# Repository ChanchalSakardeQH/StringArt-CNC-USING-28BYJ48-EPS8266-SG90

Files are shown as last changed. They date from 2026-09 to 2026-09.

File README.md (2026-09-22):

# ESP8266 String Art CNC

An ESP8266 string art machine you drive from your phone. A 28BYJ-48 stepper
turns a disc of nails, an SG90 servo hooks the thread onto each one, and a
0.96" OLED shows where it is in the sequence.

Everything runs on the board itself. The web page it serves turns a photo into
a nail sequence, designs a printable base template for the nail ring, sends the
sequence to the machine and drives it — with no app, no desktop software and no
internet connection.

---

## Contents

- [Features](#features)
- [Repository layout](#repository-layout)
- [Hardware](#hardware)
- [Wiring](#wiring)
- [Flashing](#flashing)
- [First run](#first-run)
- [Setting up a new machine](#setting-up-a-new-machine)
- [Making a piece](#making-a-piece)
- [How the wrap works](#how-the-wrap-works)
- [The OLED display](#the-oled-display)
- [Electronics enclosure](#electronics-enclosure)
- [Power cuts](#power-cuts)
- [When the wrong nail turns up](#when-the-wrong-nail-turns-up)
- [Checkpoint test run](#checkpoint-test-run)
- [Which gear ratio](#which-gear-ratio)
- [Configuration in the sketch](#configuration-in-the-sketch)
- [HTTP API](#http-api)
- [Files on flash](#files-on-flash)
- [Troubleshooting](#troubleshooting)
- [Tests](#tests)
- [Known limitations](#known-limitations)
- [Licence](#licence)
- [Credits](#credits)

---

## Features

- **Photo to string art in the browser** — upload, crop, choose nail and chord
  counts, and watch the solver build the image. Download the steps as text or
  the result as SVG.
- **Greeting card PDF** — the photo and finished art on one A4 landscape sheet,
  folded down the middle, with an optional title and message.
- **Base template designer** — a printable, numbered nail ring sized to your
  disc, with SVG export and an optional laser-cut outline.
- **Automatic thread wrapping** — the disc and servo together trace a loop
  around each nail, following the direction of travel so it works whichever
  way the chord runs.
- **Everything tuned by eye** — servo angles and the disc's wrap positions are
  sliders the hardware follows live as you drag.
- **Calibration** — re-sync the nail at the feeder, measure the real
  steps-per-turn, and re-home periodically on long runs.
- **Checkpoint test run that learns** — optionally stops every N nails to ask
  whether the right nail is at the feeder, fixes the run from your answer, and
  works out the real steps-per-turn from a series of them.
- **Resume after a power cut**, with detection of a move that was interrupted.
- **Live time estimate** from measured cycle times, not guesses.
- **OLED dashboard** showing the current and next nail, progress, time left,
  and the IP address at boot.
- **Printable electronics enclosure** — a 6.3 × 3.3 × 5 in box with the OLED
  set into its front, a lid, and a universal component tray. Plus a desk stand
  for the display.
- **No extra libraries** — builds on the bare ESP8266 core.
- **Free software** — GPL v3 or later, with every outside author credited.

---

## Repository layout

```
esp8266_string_art_standalone.ino   firmware
web_page.h                          the web UI, one PROGMEM string
oled_display.h                      OLED driver and dashboard

parts.py                            machine parts -> stl/
fitcheck.py                         checks every machine-part bolt fits
assembly.py                         renders the assembled machine
enclosure.py                        electronics box, lid, tray, OLED mount -> stl/
enclosure_fitcheck.py               checks every enclosure part fits
enclosure_render.py                 renders enclosure_guide.png
stl/                                all the printed parts
PRINTING.md                         printing and assembly guide

tests/                              firmware compile, regression + end-to-end tests
  run.sh  auto_start.cpp  checkpoint_e2e.cpp  page_auto.js  stub/

oled_wiring.png  oled_screens.png  assembly_guide.png  enclosure_guide.png
README.md  CHANGELOG.md  LICENSE  THIRD_PARTY_NOTICES.md
```

The Arduino IDE needs the `.ino` to sit in a folder with the same name. Clone
the repo into a folder called `esp8266_string_art_standalone`, or copy the
three firmware files into one.

**The three firmware files must stay together.** `web_page.h` is separate
because the Arduino preprocessor corrupts very large raw string literals in
`.ino` files but leaves `.h` files alone. `oled_display.h` is separate so its
drawing code can be compiled and tested on a PC.

---

## Hardware

| Part | Notes |
|---|---|
| ESP8266 board | NodeMCU 1.0 or similar |
| 28BYJ-48 stepper + ULN2003 board | 5 V version |
| SG90 micro servo | The thread hook |
| External 5 V supply | 2 A. Powers the motor and servo — never run them from the ESP8266's regulator |
| 0.96" OLED, SSD1306, I2C | *Optional.* 128×64. Four-pin I2C modules only, not SPI |
| Microswitch + 10 kΩ resistor | *Optional.* Home position sensor |
| Nail disc | Plywood or MDF, nails around the rim |
| Thin tube | Brass or steel, about 2 mm, for the thread to run through |

For the thread to stay on a nail, three things must be true, and none of them
can be fixed in firmware: the nails need heads (panel pins or brads, not
headless pins), the tube must carry the thread past the outside of the nail
ring at shank height, and the spool needs light tension.

---

## Wiring

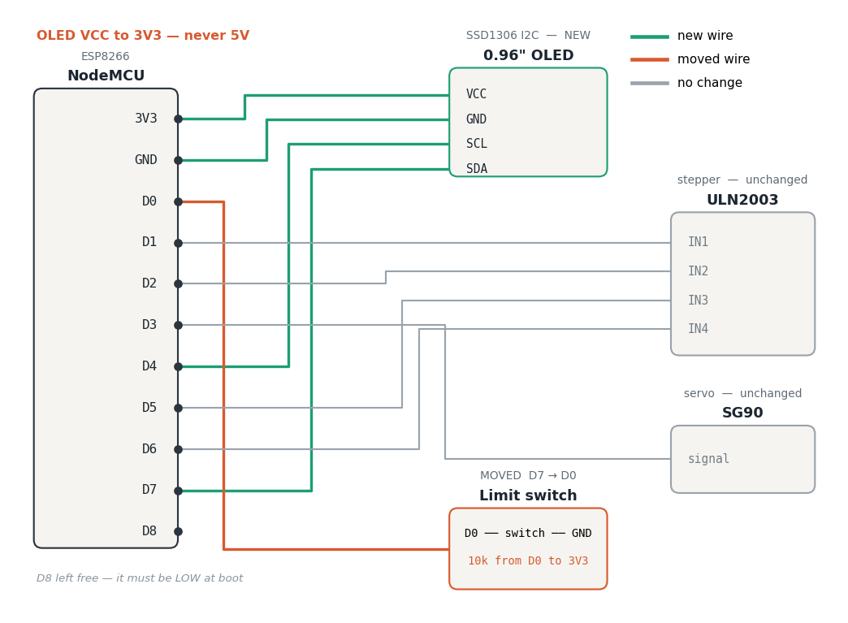
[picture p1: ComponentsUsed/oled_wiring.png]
Wiring diagram


```
ULN2003 IN1  ->  D1  (GPIO5)
ULN2003 IN2  ->  D2  (GPIO4)
ULN2003 IN3  ->  D5  (GPIO14)
ULN2003 IN4  ->  D6  (GPIO12)
ULN2003 +    ->  external 5 V
ULN2003 GND  ->  common ground

SG90 signal  ->  D3  (GPIO0)
SG90 V+      ->  external 5 V
SG90 GND     ->  common ground

OLED VCC     ->  3V3            3.3 V -- never 5 V
OLED GND     ->  GND
OLED SDA     ->  D7  (GPIO13)
OLED SCL     ->  D4  (GPIO2)

Limit switch ->  D0  (GPIO16) and GND
10k resistor ->  from D0 to 3V3
```

**Share ground, not power.** The motor and servo draw current spikes the
ESP8266's regulator can't supply while WiFi is transmitting. Feed them from the
external 5 V supply and tie every ground together.

**Power the OLED from 3V3.** Its I2C pull-up resistors connect to whatever
powers it, and the ESP8266's pins are not 5 V tolerant.

**SCK and SCL are the same pin.** Many 4-pin OLED modules label the clock
**SCK** instead of SCL; wire it to D4 all the same. Check the pin count first,
though: a module with 6 or 7 pins (RES, DC, CS and so on) is the SPI version,
and SCK means something different there. The firmware only supports I2C.

**Upgrading from before 1.12.0?** The limit switch used to be on D7. It has
moved to D0 to make room for the display, and now needs the 10 kΩ resistor.
See the [changelog](CHANGELOG.md) for the full list.

### Why the pins are where they are

The ESP8266 has few free pins, and several have jobs at boot.

- **D1 and D2** are the usual I2C pair, but they drive the stepper.
- **D8** must be LOW at boot. An I2C pull-up would hold it HIGH and the board
  would not start.
- **D0** cannot do I2C — it sits on a separate register the driver can't use.
- That leaves **D4 and D7** for the display, which pushes the limit switch to
  **D0**.
- **D0 has no internal pull-up**, so the switch needs the 10 kΩ resistor to
  3V3. Without it the pin floats and homing reads noise.
- **D3 and D4** must read HIGH at reset. The servo input and the OLED's
  pull-up both leave them HIGH, so the board boots normally.
- **D4** also drives the onboard blue LED on most boards. It flickers faintly
  while the display updates. That is harmless.

---

## Flashing

1. In the Arduino IDE Board Manager, install **esp8266** by ESP8266 Community.
2. **Tools → Board** → *NodeMCU 1.0 (ESP-12E Module)*, or your board.
3. **Tools → Flash Size** → any option with a LittleFS partition.
4. Open the `esp8266_string_art_standalone` folder containing the three firmware files.
5. Set `WIFI_SSID` and `WIFI_PASSWORD` near the top of the `.ino`.
6. If you fitted the limit switch and resistor, set `HAS_LIMIT_SWITCH = true`.
7. Upload.

No libraries to install. WiFi, the web server, mDNS, LittleFS, Servo and Wire
all come with the ESP8266 core, and the OLED driver is in `oled_display.h`.

---

## First run

Power it up and watch the OLED. It shows **Joining WiFi**, then the IP address
to open and `stringart.local`, for eight seconds.

If it can't join your network it starts its own: an open network called
**StringArtCNC**. Connect to it and open **192.168.4.1**. The OLED shows this
too.

Without a display, the address is printed on the serial monitor at 115200 baud.
With no sequence loaded, the OLED keeps showing the address until you load one.

---

## Setting up a new machine

Do these once, in this order. Each step depends on the one before it.

**1. Set the nail count.** Section 1 · Design → **Nails**. This one value is
shared by the design, the base template and the machine, so it only needs
setting once. Settle on it before tuning anything else — changing it later
resets the wrap settings, because step counts don't carry over to a different
nail spacing.

**2. Print and fit the base template.** Section 4 · Base template. Print the SVG
at 100% scale with fit-to-page turned off, glue it face up on the disc, and
drill at every red dot. Nail 0 is at three o'clock and numbering runs
clockwise.

**3. Home the disc.** Line nail 0 up with the feeder and press **Set Home**. With
a limit switch fitted, press **Find Home (limit switch)** instead.

**4. Check the direction.** Advanced settings → Motor → **Run direction test**.
The disc visits nails at the quarter points. If the nail arriving at the feeder
isn't the one named on screen, turn on **Reverse rotation direction** and home
again.

**5. Set the servo angles.** Advanced settings → Feeder servo (SG90) angles.
Drag the sliders and the arm follows. **Rest** sits clear of the nails; **Feed**
has the tube out past the ring. **Swing rest → feed → rest** plays the real
motion.

**6. Set the wrap.** Advanced settings → Wrap cycle. Drag **Ahead of the nail**
and **Behind the nail**; the disc follows. The defaults are half a nail each
way. Then use **Walk through one wrap by hand**, one button at a time, with
thread on. If it hooks by hand it will hook on the run. Turn on **Preview as if
the disc arrived travelling −** and walk through again to check the other
direction.

**7. Measure the steps per turn** *(recommended before long pieces)*. Section 2 ·
Wrap → Calibrate the nail position. **Spin** ten turns, then enter how many
nails past the start it finished and press **Correct**.

---

## Making a piece

**Design.** In section 1, choose a photo, crop it to the circle, set the chord
count and line weight, and press **Generate string art**. More chords make a
darker, more detailed result and a much longer wrap. Download the steps or an
SVG if you like.

**Greeting card.** Under the Design section, **Greeting card (A4 PDF)** puts your
photo and the finished art on one A4 landscape sheet: art and title on the
cover, photo and message inside. Print at 100% with fit-to-page off.

**Send.** Press **Send to this machine**.

**Wrap.** In section 2 the large number is the nail at the feeder. **Next →**
advances one nail; **Start Auto** runs the sequence hands-free with a pause
between nails. Under the progress bar you get elapsed time, time left, the
clock time it will finish, and seconds per nail.

**Go to step #** jumps to a point in the sequence and carries on from there.
**Go to nail #** turns the disc without changing your place.

---

## How the wrap works

A feeder that swings out and back along the same line cannot hook a nail. That
path encloses nothing, so the thread touches the nail and lets go. The tube has
to travel around the nail. With one servo, the disc supplies half of that loop:

| Phase | What moves | Default |
|---|---|---|
| Approach | Disc, to just past the nail | — |
| Settle | Nothing — let the disc stop | 800 ms |
| Tube in | Servo swings to the feed angle | 900 ms |
| Wait | Let the thread seat | 400 ms |
| Sweep | Disc, back across the nail | — |
| Wait | Let the thread hook | 400 ms |
| Tube out | Servo swings back to rest | 900 ms |
| Recover | Let the thread settle | 400 ms |
| Land | Disc onto the nail | — |

The loop takes its direction from the way the disc travelled to reach the nail:
it runs past the nail, sweeps back across, and lands. The thread always trails
behind the direction of travel, so this keeps the tube on the far side from it.
A loop with a fixed direction wraps correctly one way round and drops the thread
the other.

The servo is moved a couple of degrees at a time rather than sent straight to
its angle. `Servo.write()` has no speed setting, so an SG90 otherwise slams to
position.

All the timings are in Advanced settings → Timings. If the thread snatches,
raise **Settle before feed** first. Usually the disc hasn't stopped moving yet.

---

## The OLED display

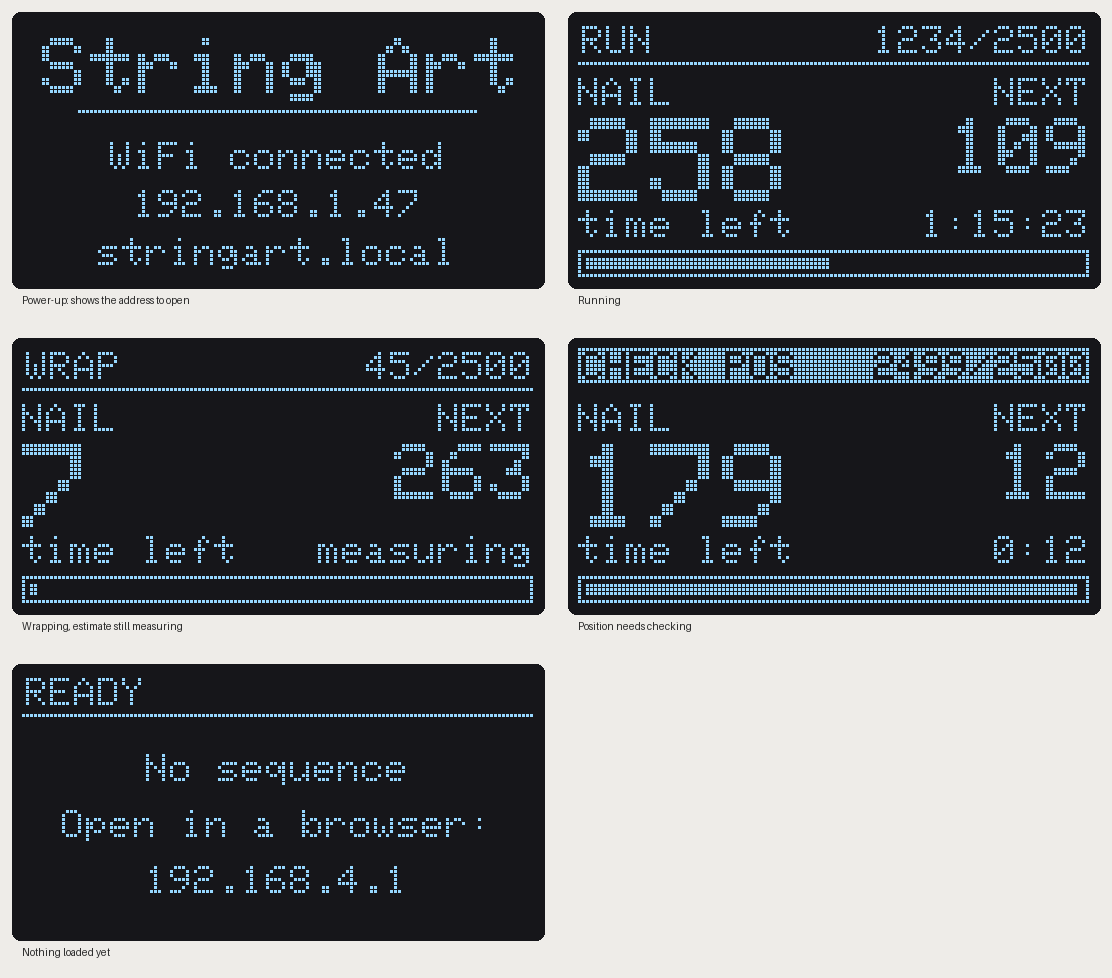
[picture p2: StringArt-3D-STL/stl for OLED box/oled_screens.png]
OLED screens


- **Header:** the machine's state — RUN, WRAP, FEED, HOMING, PAUSED, DONE — and
  the step count. It turns into a highlighted bar for **CHECK POS** (position
  not verified after a power cut) or **HOME FAIL**.
- **Centre:** the nail at the feeder in large digits, and the next nail.
- **Bottom:** a live countdown of time left, and a progress bar.

The display is found automatically at address 0x3C or 0x3D. If none is
connected, the firmware carries on without it. If the text comes out upside
down, turn on **OLED display upside down** in Advanced settings → Motor.

It never slows the machine down. It skips redrawing while the disc is moving,
sends the picture in small pieces between other work, and sends nothing when
the numbers haven't changed.

---

## Electronics enclosure

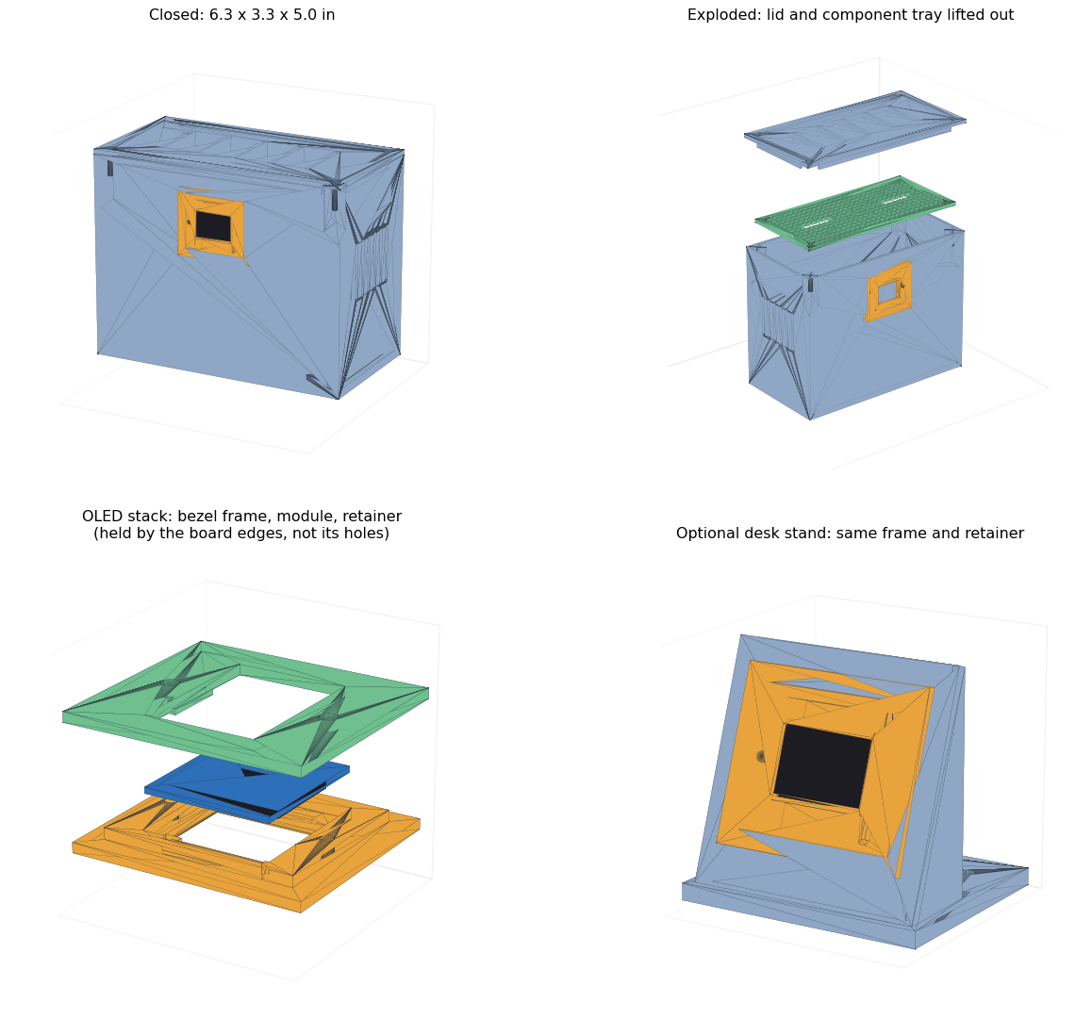
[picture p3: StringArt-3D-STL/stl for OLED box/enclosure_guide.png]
Enclosure


A box for the NodeMCU, the ULN2003 board and the wiring, with the OLED set into
its front. **6.3 × 3.3 × 5 in outside with the lid on** (160 × 84 × 127 mm);
inside it's 155 × 79 × 121 mm. Every size is a named constant at the top of
`enclosure.py`.

| Part | Print it | What it does |
|---|---|---|
| `enclosure_box.stl` | Upright, open top up | The box. OLED opening in front, cable port and DC jack hole in the back, vents in both ends |
| `enclosure_lid.stl` | Outer face down | Screws onto four corner bosses |
| `enclosure_tray.stl` | Flat | Perforated plate on four standoffs. The 0.1 in hole grid takes M2.5 or M3 self-tapping screws or cable ties, so any board fits without knowing its hole pattern |
| `oled_frame.stl` | Front face down | The bezel. Holds the display by its board edges |
| `oled_retainer.stl` | Flat, fingers up | Clamps the frame to the wall and keeps the display in |
| `oled_stand.stl` | On its base | *Optional.* Desk stand for the display. Uses the same frame and retainer |

None of them need support. The box's OLED opening has a 38 mm flat top edge,
which most printers bridge cleanly. The box needs a bed of at least
165 × 90 mm and 130 mm of height.

### How the display is held

The frame goes in from the front, and the retainer goes on from inside. Two
screws through the retainer into the frame clamp the wall between them, and at
the same time the retainer's two fingers keep the display's board seated in its
pocket. So the same two screws do both jobs, and nothing shows on the front.

The display is held **by its board edges, not its mounting holes.** The drawing
it was designed from gives the board, glass and flex-cable sizes, but not the
hole spacing — so nothing depends on it. The fingers leave the board 0.1 mm of
play rather than squeeze the glass.

### One measurement before printing the frame

The drawing doesn't say exactly where the glass sits up the board. Measure the
distance from the **top edge of the board** (the pin header side) to the **top
of the black glass**, and set `GLASS_TOP` in `enclosure.py`. The default, 5.5 mm,
assumes the glass is centred. The glass pocket allows 1 mm either way, so
anything close is fine. The frame is a 4 cm³ print, so a second try costs
about fifteen minutes; the box never needs reprinting for this.

### Screws

| Where | What |
|---|---|
| Lid to box | 4 × M3 × 8 countersunk, self-tapping |
| Tray to standoffs | 4 × M3 × 6 self-tapping |
| OLED retainer to frame | 2 × M3 × 6 self-tapping |
| Box to machine base | 4 × M3, through the floor |
| Boards to tray | M2.5 or M3 self-tapping, or cable ties |

After changing anything in `enclosure.py`, run it, then
`enclosure_fitcheck.py`. The check places every part in its assembled position
with a model of the display, and confirms nothing collides, that the bezel and
retainer really clamp the wall, and that every screw meets its hole.

---

## Power cuts

The disc holds its position when the power goes, so nothing physically moves.
What matters is whether the firmware still knows where the disc is. Progress is
saved twice per nail — when a move starts and when it lands — which covers both
cases:

- **Cut while stopped between nails:** the saved position is exact. It picks up
  on the same step.
- **Cut during a move:** the disc stopped somewhere between two nails. The
  firmware restores where it was heading, marks the position unverified, and the
  OLED and web page show **CHECK POS**. Home before carrying on. Your progress is
  kept either way.

With a limit switch, **Find home on power-up** (Advanced settings → Motor) homes
automatically at boot and drives back to the saved nail. It does not restart the
run on its own, since the thread may be loose.

---

## When the wrong nail turns up

On a long run the nail at the feeder can stop matching the one on screen. There
are three different causes, and they need different fixes.

**Out by the same amount every time.** Section 2 · Wrap → Calibrate the nail
position. Jog the disc until the right nail lines up, then enter which nail it is
and press **Set**. Your place in the sequence is untouched.

**A little further out with every turn.** The steps-per-turn figure is wrong.
**Spin** ten turns, enter how far past the start it finished, and press
**Correct**. Ten turns can measure an error of 0.05%.

**Wandering at random, even after both fixes.** The motor is losing steps. The
28BYJ-48 can't sense this, so the fixes are mechanical: raise the step delay,
make the disc lighter, and check nothing is rubbing. **Re-home every N nails**
(needs the limit switch) keeps a long run on track, but it works around the
problem rather than fixing it.

---

## Which gear ratio

The 28BYJ-48 is sold as a 64:1 gearbox, which gives **4096** half-steps per
turn of the output shaft. That's what the firmware starts with. Many units are
actually **63.68395:1** — the ratio you get by multiplying out the real gear
teeth — which gives **4075.77**. The difference is about half a percent, or
roughly 1.8° by the time the disc has gone once round.

You don't have to know which one you have. Section 2 · Wrap → Calibrate the
nail position → **Spin** ten turns, enter how many nails past the start it
finished, and press **Correct**. The firmware works out the real figure and
saves it. A disc that finishes 18 nails short over ten turns measures 4075.6 —
the tooth-count ratio, found by measurement.

Within a single turn the choice barely matters: rounding to the nearest
half-step is at most ±0.044°. It only shows up as error that builds over whole
turns.

---

## Checkpoint test run

A calibration run you do with thread on, on a real sequence. **It's off by
default.** Turn it on in Section 2 · Wrap → Calibrate the nail position →
**Pause to check the nail during a run**, pick how often, and start the run.

Every Nth nail, the disc stops **on** the nail, before wrapping, and asks:

> Checkpoint: is nail **258** centred in front of the feeder?

- **If it is**, press **Yes, it's centred**.
- **If it's slightly off**, use the nudge buttons (±1 step, ±1 nail) until it's
  centred, then press **Yes**. The nudge is measured to the step, and that
  precision is what lets it learn.
- **If it's well off**, type the nail that's actually there and press **Use**.
- **Skip this checkpoint** carries on without learning from it.

The OLED shows **CONFIRM?** and the browser tab gets a ● marker while it's
waiting, so a question isn't missed during a long run.

### What your answers do

**They fix the run straight away.** Each answer re-syncs the numbering, then
the machine wraps that nail and carries on.

**They teach it.** The firmware plots the total correction so far against how
far the disc has turned, and fits a straight line through the answers:

- a **constant error** — the same every time — is a position offset;
- an error that **grows as the disc turns** means the steps-per-turn figure is
  slightly wrong, and the slope says by how much;
- answers that **don't fall on a line** mean missed steps. Those are random and
  can't be learned; the panel says so and points you at the mechanics instead.

It only believes a slope once it has **5 checkpoints spread over 2 turns** and
at least two nails' worth of drift. Until then it only corrects the offset.
With **Correct steps per turn automatically** on (the default), it applies the
new figure at the next checkpoint and tells you what changed. Turn that off to
review the suggestion and apply it with **Use suggested steps per turn**.
**Forget what it learned** puts steps-per-turn back to what it was.

### How long a test run takes

With a question every 25 nails, it learned the steps-per-turn at the **6th
checkpoint**, about 150 nails in, for motors both slower and faster than the
firmware assumed. **Plan on 8–10 checkpoints.** Turning checkpoints off before
it has learned leaves the motor uncalibrated — the run carries on, but the drift
it was about to correct stays.

### Does it work?

It was tested by running the real firmware — `setup()`, `loop()` and the web
handlers — on a PC, against a simulated disc whose true steps-per-turn differed
from what the firmware assumed, answering every question as a person would.
Each run is 600 nails with a checkpoint every 25:

| Motor | Answers | Steps/turn learned | Wrong nails, last 200 |
|---|---|---|---|
| 4075.77 steps/turn | nudged to centre | 4075.65 | 0 |
| 4110.00 steps/turn | nudged to centre | 4109.94 | 0 |
| 4096.00 (already right) | nudged to centre | unchanged | 0 |
| 4075.77 steps/turn | whole nails only | within 0.9 steps | up to 30% |

So **centring before you answer matters a lot**. A whole-nail answer can leave
the disc up to half a nail off, and a tiny drift then tips it onto the
neighbouring nail. With a motor that's already right, it never changes
anything. `sh tests/run.sh` repeats these runs — see [Tests](#tests).

After a test run has settled the steps-per-turn, turn checkpoints off for
normal runs.

---

## Configuration in the sketch

Most settings live in the web page and are saved to flash. These few are set in
the `.ino` before uploading:

| Constant | Default | Purpose |
|---|---|---|
| `WIFI_SSID`, `WIFI_PASSWORD` | placeholders | Your network |
| `AP_FALLBACK_SSID` | `StringArtCNC` | Network it starts if yours fails |
| `HOSTNAME` | `stringart` | Reached at `stringart.local` |
| `HAS_LIMIT_SWITCH` | `false` | Set `true` once the switch and resistor are fitted |
| `MOTOR_GEAR_RATIO_X100000` | `6400000` | 64:1. A starting point only — see [Which gear ratio](#which-gear-ratio) |
| `DEF_*` | see file | Values used on first boot and by **Restore defaults** |

**Restore defaults** in Advanced settings puts every web setting back to the
`DEF_*` values without re-flashing.

---

## HTTP API

The page talks to the machine over four endpoints, all CORS-enabled.

| Method | Path | Purpose |
|---|---|---|
| `GET` | `/` | The web page |
| `GET` | `/status` | JSON: position, progress, timings, every setting, detected hardware |
| `POST` | `/upload` | The sequence, one nail number per line |
| `POST` | `/config` | Form fields for any setting; `reset=1` restores defaults; `recalcWrap=1` recomputes the wrap for the nail count |
| `POST` | `/action` | `cmd=` plus `value=` where needed |

**Actions:**

| `cmd` | `value` | Does |
|---|---|---|
| `next`, `prev` | — | Move one step through the sequence |
| `start`, `stop` | — | Auto-run on or off |
| `gotostep` | step | Jump to a step, taking progress with it |
| `goto` | nail | Turn the disc to a nail, progress unchanged |
| `home` | — | The nail at the feeder becomes nail 0 |
| `findhome` | — | Seek the limit switch. Refused if none is fitted |
| `feed` | — | One servo cycle, rest → feed → rest |
| `wraptest` | — | One full wrap on the current nail |
| `wrappreview` | steps | Park the disc this many steps from the current nail |
| `servotest` | angle | Move the servo to an angle |
| `jog` | steps | Nudge the disc without changing the numbering |
| `setnail` | nail | "The nail at the feeder is this one" — re-syncs |
| `calmove` | turns | Spin whole turns for steps-per-turn calibration |
| `calreport` | nails | Report how far past the start it finished |
| `verify` | nail, `-1` or `-2` | Answer a checkpoint: the nail really at the feeder, `-1` "yes, centred", `-2` skip |
| `learnapply` | — | Use the steps-per-turn the checkpoints suggest |
| `learnforget` | — | Clear what the checkpoints learned and restore the previous steps-per-turn |

```bash
curl http://stringart.local/status
curl -X POST http://stringart.local/action -d "cmd=goto&value=258"
curl -X POST http://stringart.local/config -d "feederSettleMs=1000"
```

---

## Files on flash

| Path | Contents |
|---|---|
| `/sequence.csv` | The nail sequence, one number per line |
| `/state.txt` | Step, disc position, target, whether a move was in progress, elapsed time, average time per nail |
| `/config.txt` | Every setting, one value per line |

Settings files from older firmware load fine. Any value that's missing falls
back to its default rather than zero.

---

## Troubleshooting

**The wrong nail arrives, and it's always the mirror image** — you ask for 258
and get 102. The rotation direction is reversed. Turn on **Reverse rotation
direction** in Advanced settings → Motor, then home again.

**The thread hooks on some nails but not others.** Check both approach
directions with **Test wrap, coming from −** and **Test wrap, coming from +**.
Both should make the same small reversing move at the nail. If both do but the
thread still drops, go through the three mechanical checks under
[Hardware](#hardware): nail heads, the tube crossing the ring, and spool tension.

**Start Auto does nothing.** Look at the line under the button: it says why
auto isn't moving — the sequence is finished, it's waiting for a checkpoint
answer, a calibration spin is running, or it's homing. If nothing shows and the
button still says Start Auto after you press it, the page isn't reaching the
board: check the IP on the OLED and reload. After flashing new firmware, reload
the page too, so the browser isn't running the old copy.

**The motor hums but doesn't turn.** The step delay is too short for the load,
or a coil wire is loose. Raise the step delay to 3–5 ms first. If it still
won't move, check that the four LEDs on the ULN2003 light in sequence.

**Find Home never completes.** Check that `HAS_LIMIT_SWITCH` is `true`, that
the switch connects **D0** to GND when pressed, and that the 10 kΩ resistor
runs from D0 to 3V3. Without the resistor D0 floats and never reads cleanly. The
status line shows the switch's live state, so press it by hand and watch it
change. The search gives up after a turn and a quarter and reports **HOME FAIL**.

**Find Home does nothing at all.** `HAS_LIMIT_SWITCH` is `false`, so homing is
refused. Use **Set Home** instead: line nail 0 up with the feeder by hand and
press it.

**The OLED stays blank.** Check that it's powered from 3V3, that SDA goes to D7
and SCL to D4 (swapping them is the most common mistake), and that it's an I2C
module — four pins marked VCC, GND, SCL, SDA. The web page shows **Display
found at 0x3C**, or says none was detected.

**The board won't boot after wiring the OLED.** Something is holding D3 or D4
LOW at power-up. Check the OLED isn't wired to D8, and that nothing else is
connected to D4.

**The thread snatches or feeds unevenly.** Raise **Settle before feed** in
Advanced settings → Timings. The disc usually needs longer to stop than it looks.

**The page loads but the buttons do nothing.** Check the IP on the OLED. A
bookmarked address stops working when your router hands out a new one.

**It's on 192.168.4.1 instead of your network.** It couldn't join your WiFi and
started its own. Check the network name and password — and note the ESP8266
only works with 2.4 GHz networks, not 5 GHz.

---

## Tests

```bash
sh tests/run.sh
```

Needs only `g++`. It runs four stages:

1. **Compiles the whole firmware** on a PC, against stand-in versions of the
   ESP8266 core's headers in `tests/stub/`, with all compiler warnings on. This
   catches typos, missing declarations and type errors anywhere in the sketch
   without the Arduino IDE or a board.
2. **Start/Stop Auto regressions**: the real firmware, checked for the first
   move starting straight away, auto-run surviving a calibration spin, and
   Start refusing a finished sequence with a reason.
3. **The checkpoint feature end to end**: the real `setup()`, `loop()` and
   web handlers, on a simulated disc, for three motors.
4. **The web page**: checks the firmware's real `/status` reply is valid JSON,
   then — if `jsdom` is installed — loads the real page and clicks Start and
   Stop Auto. To enable that part: `cd tests && npm install jsdom`.

The stand-ins only need to be close enough to compile and drive the firmware;
they aren't a full emulator. A clean run here doesn't replace flashing the
board, but it catches most mistakes long before that.

The printed parts have their own checks: `fitcheck.py` and
`enclosure_fitcheck.py`.

---

## Known limitations

- **The stepper can't sense missed steps.** The 28BYJ-48 has no feedback, so a
  missed step goes unnoticed until the wrong nail arrives. The limit switch and
  periodic re-homing work around this; they don't prevent it.
- **The 28BYJ-48 is weak.** It has little torque above about 15 rpm. A heavy
  disc or a short step delay will make it lose steps.
- **Wrapping depends on the mechanics.** The firmware controls the timing and
  the path, but whether the thread stays on depends on nail shape, tube position
  and thread tension. Expect to tune these on your own machine.
- **Only one servo axis.** The disc has to make half of each wrap loop, so every
  nail costs two short extra moves.

---

## Licence

ESP8266 String Art CNC is free software: you can redistribute it and/or modify
it under the terms of the **GNU General Public License, version 3 or (at your
option) any later version** — see [LICENSE](LICENSE). It comes with no
warranty.

In short: anyone can use, study, change and share it, including commercially,
but anything distributed that's built from it must also be under the GPL, with
its source available. The web page shows this notice at the bottom of the
sidebar, as the GPL asks interactive programs to.

Each source file starts with an `SPDX-License-Identifier` line. Two files also
contain other people's work under their own licences:

| File | Licence |
|---|---|
| `web_page.h` | GPL-3.0-or-later AND MIT (bundles Cropper.js) |
| `oled_display.h` | GPL-3.0-or-later AND BSD-2-Clause (the 5×7 font) |

---

## Credits

This project builds on other people's work. Their credits and licences are kept
as they were, in the files themselves and in full in
[THIRD_PARTY_NOTICES.md](THIRD_PARTY_NOTICES.md).

- **Cropper.js** 1.6.1 by **Chen Fengyuan** — MIT. Bundled into the web page,
  unmodified, with its copyright banner.
- **5×7 font** ("glcdfont") by **Adafruit Industries**, from Adafruit-GFX-Library
  — BSD 2-Clause. The OLED driver around it was written for this project.
- **Base template designer** and coding of  *StringArt-Design* by
  **Chanchal Sakarde**.

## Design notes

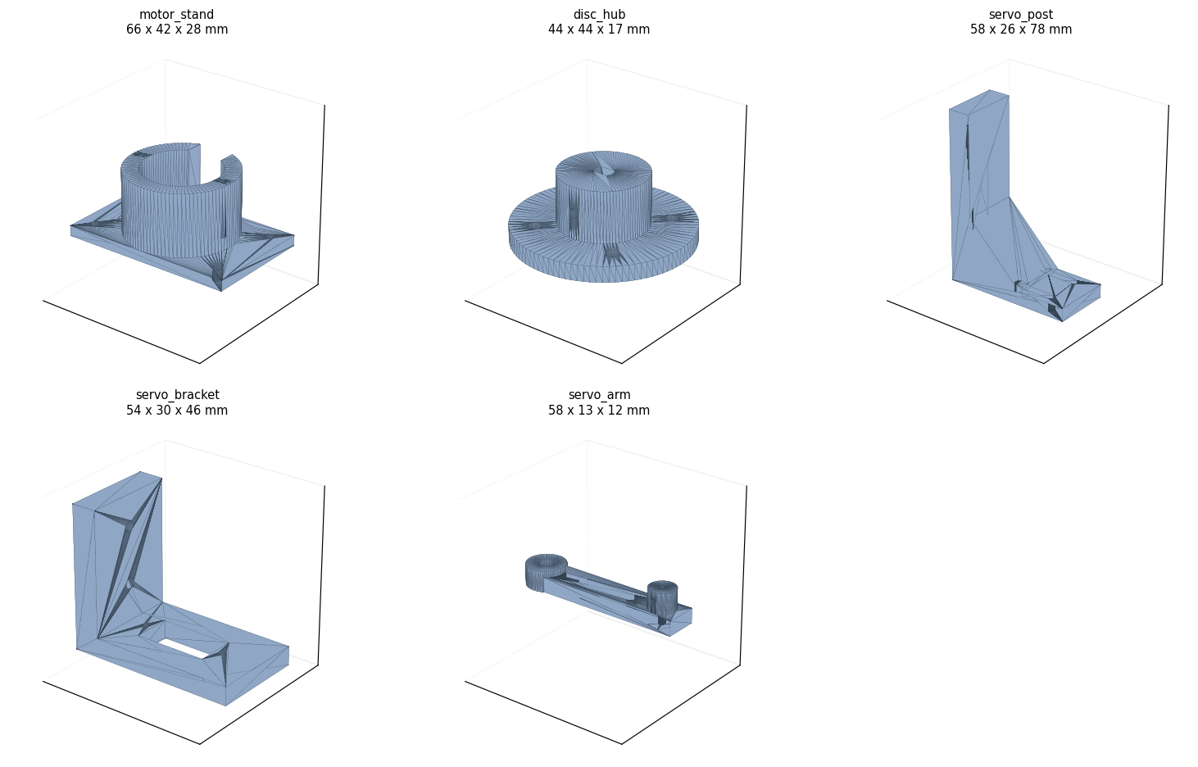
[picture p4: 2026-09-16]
StringArt-3D-STL/preview.png

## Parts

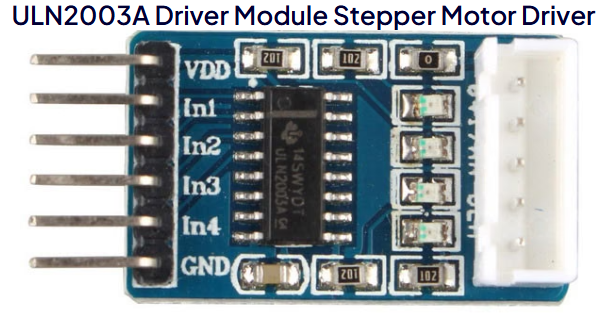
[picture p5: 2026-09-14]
ComponentsUsed/ULN2003A-DriverModule.png

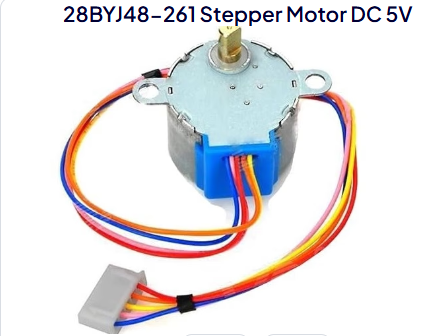
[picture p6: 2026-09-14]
ComponentsUsed/28BYJ48-261StepperMotorDC5V.png

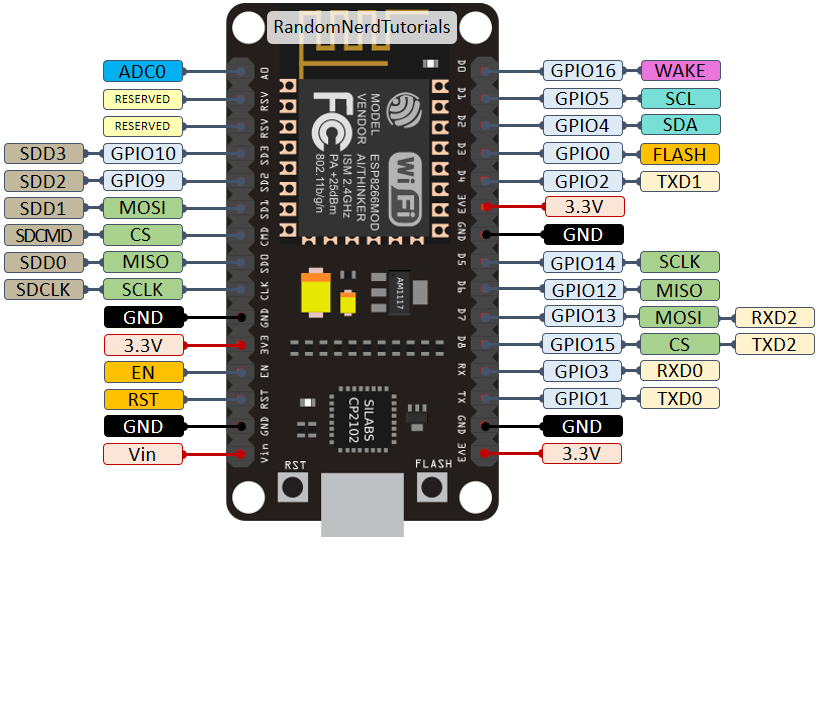
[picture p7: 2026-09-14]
ComponentsUsed/ESP8266-pin.png

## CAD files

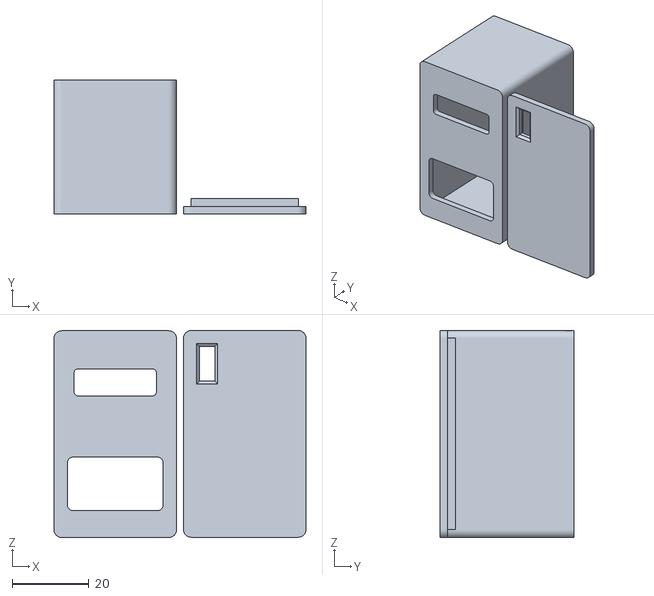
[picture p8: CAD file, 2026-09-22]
StringArt-3D-STL/stl for OLED box/case_v11.stl
65.8 x 35.0 x 54.1

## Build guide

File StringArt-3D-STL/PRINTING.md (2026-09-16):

# Printed parts — String Art CNC

Five parts, all watertight and all designed so nothing needs support.
`parts.py` regenerates every STL; every dimension is a named constant at the top.

```bash
pip install trimesh manifold3d shapely numpy matplotlib
python3 parts.py      # writes the five STLs
python3 fitcheck.py   # proves every bolt path is clear
python3 assembly.py   # redraws assembly_guide.png
```

---

## Read this before printing

Three numbers in `parts.py` are **guesses**, because I don't know your machine:

```python
NAIL_RING_R = 200.0   # radius of the nail circle
NAIL_HEIGHT = 12.0    # how far the nails stand above the disc
DISC_THICK  = 6.0     # thickness of the nail disc
```

They don't change any part's geometry, but they drive the stack-up check the
script prints at the end — which tells you whether the servo column is tall
enough to put the arm at nail-shank height. Measure yours and re-run before
printing `servo_post`.

The 28BYJ-48 and SG90 are cloned by dozens of factories and vary by a few
tenths of a millimetre. The constants are nominal-plus-clearance. **Print the
disc hub first** as a fit test — it's 10 cm³ and takes about 40 minutes. If it
won't go on the shaft, raise `MOTOR_SHAFT_D`/`MOTOR_SHAFT_FLATS` by 0.1 and
reprint before committing to the rest.

---

## Parts

| File | Size | What it does |
|---|---|---|
| `motor_stand.stl` | 66 × 42 × 28 | Holds the 28BYJ-48 upright, shaft up, on the board |
| `disc_hub.stl` | 44 × 44 × 17 | D-shaft hub the nail disc bolts to |
| `servo_post.stl` | 58 × 26 × 100 | Base and column, slotted for radial and height adjustment |
| `servo_bracket.stl` | 54 × 30 × 46 | Slides on the column, holds the SG90 shaft-down |
| `servo_arm.stl` | 58 × 13 × 12 | Carries the thread tube, sweep radius adjustable |

### motor_stand

A continuous collar rather than two separate posts. The obvious design — a post
under each bracket ear — leaves only 1.4 mm of wall between each screw hole and
the motor body cutout, because the ear holes sit at ±17.5 mm and the body is
28 mm across. A self-tapper splits that. The collar braces both bosses all the
way round instead.

Motor drops in from the top, bracket rests on the collar, two M3 × 8 self-tappers
down into the bosses. The notch takes the wire connector. 5 mm of clearance under
the motor for the cable.

### disc_hub

Flange on the bed, boss upward — **in use it's inverted**: boss down over the
shaft, disc bolted to the flange on top. The blind bore gives the shaft a depth
stop. There's an M3 grub screw through the boss onto one of the shaft flats;
fit it, or the hub will creep under the wrap cycle's back-and-forth loading.

The four flange holes are on a 32 mm circle for M3.

### servo_post and servo_bracket

Both are L-shapes extruded sideways, so they print lying on their side with
zero overhang.

The column carries **two vertical through-slots**, 36 to 94 mm up from the
board, and the bracket has **four matching holes** — two rows of two, 18 mm
apart. Four bolts rather than two because the arm cantilevers well past the
nail ring and a single pair would let the bracket twist under the side load of
dragging thread around a nail.

**Shelf underside adjusts from 68 to 104 mm above the board**, which covers the
nail heads at 64.5 mm with room to spare. Bolt through with M3 × 25, nuts and
washers on the back of the column. Slacken all four to slide the height.

The base slots let you move the whole stand toward or away from the nail ring.

Run `fitcheck.py` after changing anything here. It pushes a virtual M3 through
every bolt position and reports how much material is in the way — zero means
clear. Two bugs it caught that were invisible in the render: a slot cut through
the wrong axis, so it was a blind groove rather than a through-slot, and a slot
whose lower end ran into the gusset.

Position matters more than anything else here: **the servo's pivot must sit
inside the nail ring**, with the arm long enough that the tube tip swings past
the ring and back. That's the geometry the wrap cycle depends on.

### servo_arm

The 4.9 mm bore is a press fit onto the SG90 spline — PLA takes the teeth if you
push it on warm. Bore it out and glue in the supplied horn if you'd rather.

Set the tube's sweep so the tip crosses the nail circle cleanly at shank height,
below the nail heads. `TUBE_D = 2.1` assumes a 2 mm brass tube; change it to
match whatever you use.

---

## Print settings

Nothing here is fussy. PLA is fine; PETG if the machine will sit in sun or heat.

| | |
|---|---|
| Layer height | 0.2 mm |
| Perimeters | 3 |
| Infill | 30% (40% for `servo_arm`) |
| Support | none needed on any part |
| Orientation | all parts as modelled, largest face down |

Total is about 115 cm³ — roughly 145 g, six to eight hours across all five.

`servo_arm` is the one part worth more perimeters. It's long and thin and takes
the whole side-load of dragging thread around a nail.

---

## What it looks like assembled

`assembly_guide.png` is rendered from the actual STLs at their fitted heights —
not an illustration, so what you see is what will print. `assembly.py`
regenerates it and re-checks the geometry after any change to `parts.py`.

The numbers it prints are the ones that matter:

```
tube sweeps R 141 to 231, ring at 200 -> crosses: YES
shelf underside 70.0 vs nail heads 64.5 -> 5.5 mm clearance
```

**"crosses: YES"** is the whole machine working or not. The tube's swept circle
has to straddle the nail circle, or no wrap can happen. It depends on three
numbers: pivot radius, arm length, nail ring radius. Change any of them and
re-run `assembly.py` before you print.

**Shelf clearance** is the tight one. The bracket shelf spans over the nails to
reach a pivot inside the ring, so its underside must clear the nail heads —
5.5 mm at my guessed 12 mm nail height. Taller nails eat it fast. If you end up
under about 3 mm, raise the bracket on the column slot and lengthen the tube to
suit, rather than trimming the nails.

---

## Assembly order

1. Motor into `motor_stand`, two M3 × 8 self-tappers through the bracket.
2. `disc_hub` onto the shaft, grub screw onto a flat. Check it runs true before
   the disc goes on — any wobble here is multiplied at the nail ring.
3. Disc onto the hub flange, four M3. **Home the machine and mark nail 0 now**,
   while you can still see the hub.
4. `servo_post` screwed to the board so the pivot falls inside the nail ring.
5. `servo_bracket` onto the column, height set so the arm sweeps at mid-shank.
6. `servo_arm` on the spline, tube clamped, then run **Test one wrap** from the
   web UI and adjust before tightening anything permanently.

Step 6 is where the real fitting happens. Expect to move the post radially a few
times and reprint the arm at least once with a different length — that's normal,
and it's why the arm is the cheapest part to print.

---

## What isn't here

The nail disc itself. That's the base template from the web UI (section 4),
printed at 100% and glued to ply or MDF, then drilled. It's too big to 3D print
and better in wood anyway — it stays flatter and holds nails far better.

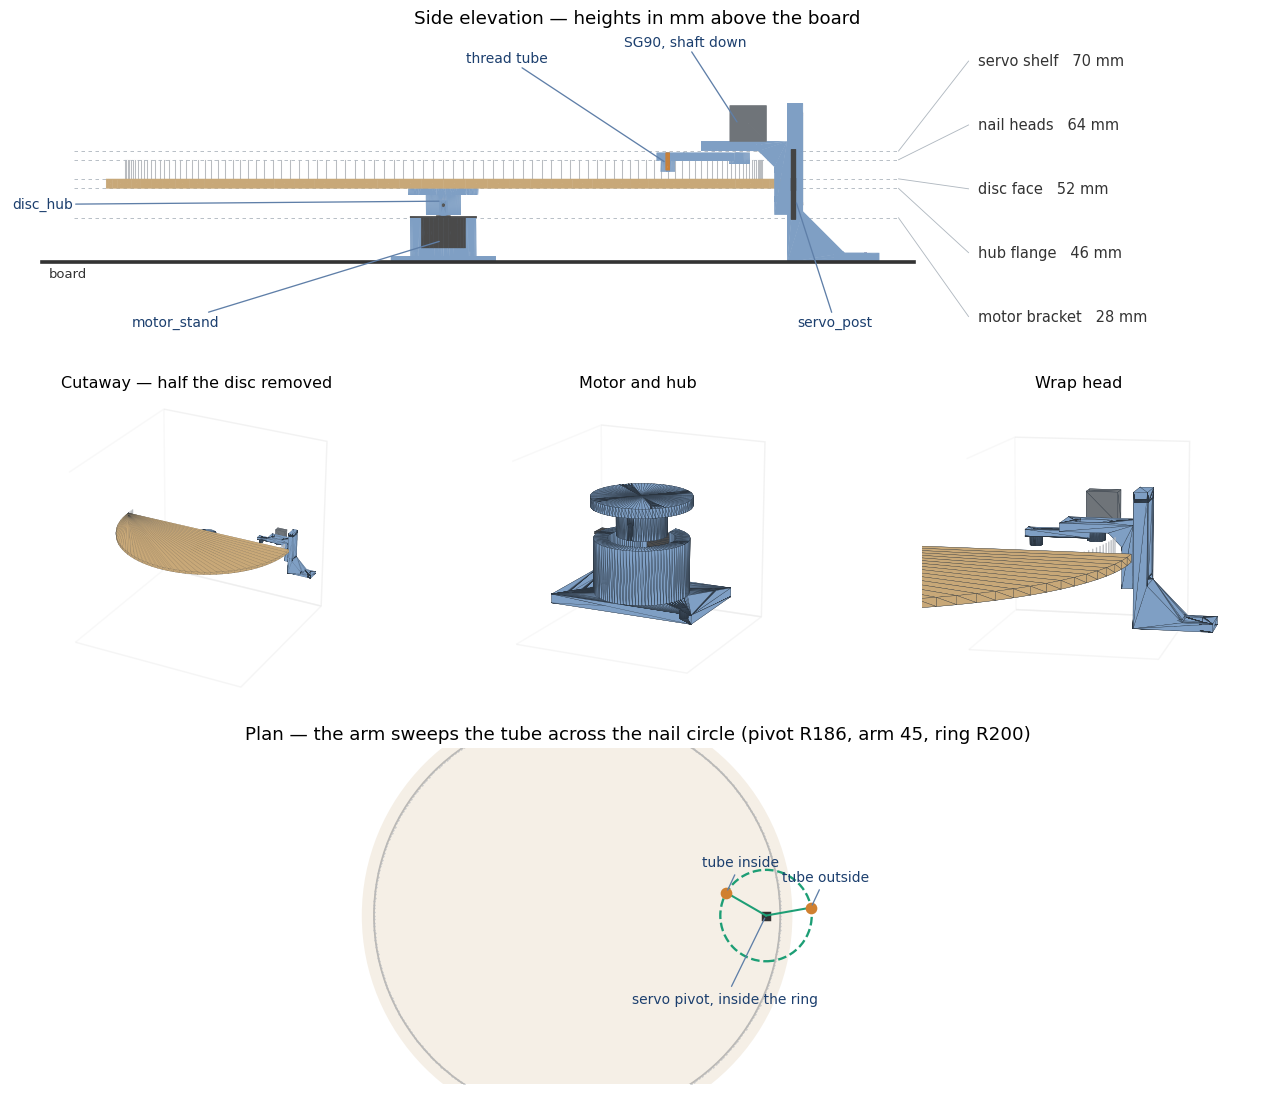
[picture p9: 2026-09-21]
ComponentsUsed/assembly_guide.png

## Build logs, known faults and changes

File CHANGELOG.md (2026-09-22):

# Changelog

All notable changes to the ESP8266 String Art CNC are recorded here.

---

## [1.14.1] — 2026-09-22

### Fixed

- **Start Auto did nothing after a calibration spin.** Pressing **Spin** in the
  calibration panel set a "calibration running" flag that only **Correct**
  cleared. Auto-run waits while that flag is set, so if you spun the disc to
  check it and moved on without pressing Correct, Start Auto switched auto on
  and then advanced no nails at all — and nothing on the page said why. The
  same flag froze the servo-angle sliders. The flag now clears the moment the
  spin finishes; Correct still works afterwards, for as long as you like.
  Reproduced in the real firmware before fixing: auto on, 0 nails advanced.
  After: all nails advanced.

- **Start Auto looked broken at the end of a sequence.** On a finished
  sequence it switched auto on with nothing left to do. It now refuses and says
  so: "The sequence is finished. Use Go to step # to start again." It also
  refuses, with a reason, when no sequence is loaded.

- **Stop** now also cancels a calibration spin in progress.

### Changed

- **The first move starts as soon as you press Start Auto**, rather than after
  a full dwell, so it's obvious the button worked.

- **The page says why auto isn't moving.** A line under the button shows a
  refused Start's reason, or whatever a running auto is waiting on: a
  checkpoint answer, a calibration spin, or homing. The rule behind it: every
  thing auto-run waits on must be visible, or a paused machine is
  indistinguishable from a broken button. `autoNote`, `autoBlock` and
  `calAwaiting` added to `/status`.

- The calibration panel tells you when a spin has finished and is waiting for
  its Correct, and that auto-run isn't held up meanwhile.

### Added

- `tests/auto_start.cpp` — regression tests for all of the above, run against
  the real firmware.
- A web page test that loads the real page in `jsdom`, feeds it the firmware's
  real `/status` reply, and clicks Start and Stop Auto. Optional; needs
  `npm install jsdom` in `tests/`.

### Removed

- Five stray `o_*.pbm` images from an OLED driver test, which had been shipped
  in the repository root by mistake. `*.pbm` is now in `.gitignore`. If they're
  in your repo: `git rm o_*.pbm`.

---

## [1.14.0] — 2026-09-21

### Added

- **Checkpoint test run** (off by default). Every Nth nail the disc stops *on*
  the nail, before wrapping, and asks whether it's centred in front of the
  feeder. Answer yes, nudge it to centre first (±1 step or ±1 nail), type the
  nail that's actually there, or skip. The answer re-syncs the numbering, then
  the machine wraps that nail and carries on.

- **Learning from the answers.** Each answer is recorded as the total
  correction so far against the net steps turned since the last home. A
  least-squares line through the points separates a constant offset (the
  intercept) from a wrong steps-per-turn figure (the slope). Once there are 5
  checkpoints over 2 turns with at least two nails' worth of drift, it corrects
  steps-per-turn — automatically by default, or on request. Answers that don't
  fit a line are reported as missed steps, which can't be learned.

- The OLED shows **CONFIRM?** and the browser tab a ● marker while a question
  is waiting. The page's panel shows checkpoints, corrections, offset, drift,
  fit quality, the suggestion, and what happened last.

- `verify`, `learnapply` and `learnforget` actions; checkpoint and learning
  fields in `/status`; `verifyEvery`, `learnAutoSpr` and the pre-learning
  steps-per-turn persisted in `/config.txt` (three more lines).

- **`tests/`**: stand-ins for the ESP8266 core's headers, so the whole
  firmware compiles on a PC with all warnings on, and an end-to-end test that
  runs the real `setup()`, `loop()` and web handlers against a simulated disc.
  `sh tests/run.sh` runs both.

### Notes

- **The whole sketch was compiled for the first time**, rather than in
  extracted pieces: no errors and no warnings with `-Wall -Wextra`.

- **Tested end to end in the real firmware.** 600-nail runs with a checkpoint
  every 25, nail nudged to centre before each answer: steps-per-turn learned as
  4075.65 for a true 4075.77, and 4109.94 for a true 4110.00, at the 6th
  checkpoint both times, with 0 of the last 200 nails wrong. With a motor that
  was already right, it changed nothing. Runs with wrapping on and off both
  finish every nail.

- **Centring matters.** With whole-nail answers only, up to 30% of nails were
  still wrong at the end: a whole-nail answer can leave the disc half a nail
  off. The page says so beside the Yes button.

- **The correction is steps/turn × (1 + slope).** The textbook-looking
  steps/turn ÷ (1 + slope) is wrong here — corrections are applied to the
  offset, which flips the sign — and would have doubled the drift instead of
  removing it. Caught in simulation before shipping, and checked for both
  rotation directions and several nail counts.

- A "yes" re-syncs to wherever the disc is at that moment, so nudging before
  answering counts as the correction. Under the earlier logic a nudge would
  have been ignored, leaving 99% of later nails wrong.

- Switching checkpoints off while a question is on screen finishes that nail's
  wrap rather than skipping the chord. Restore defaults leaves an open question
  on screen for the same reason.

---

## [1.13.0] — 2026-09-21

### Added

- **Electronics enclosure**, generated by `enclosure.py`: a box **6.3 × 3.3 ×
  5 in outside with the lid on** (160 × 84 × 127 mm), a lid on four corner
  bosses, and a perforated component tray on four standoffs. The tray's 0.1 in
  hole grid takes self-tapping screws or cable ties, so any board mounts
  without knowing its hole pattern. Cable port and DC jack hole in the back,
  vents in both ends. Everything prints without support.

- **OLED mount**: a bezel frame that goes into the box front from outside, and
  a retainer from inside. Two screws clamp the wall between them and, through
  two fingers on the retainer, keep the display seated — so nothing shows on
  the front. The display is held **by its board edges, not its mounting holes**,
  because the drawing it was designed from doesn't dimension the hole spacing.
  The fingers leave 0.1 mm of play rather than squeeze the glass.

- **Tolerance for the undimensioned glass position.** The drawing doesn't say
  where the glass sits up the board. `GLASS_TOP` sets it (default 5.5 mm, glass
  centred), and the glass pocket allows 1 mm either way. Only the 4 cm³ frame
  would ever need reprinting for a different module, never the box.

- **Desk stand** for the display, taking the same frame and retainer.

- `enclosure_fitcheck.py`: places every part in its assembled position with a
  model of the display, and checks for collisions, that the bezel and retainer
  really touch the wall (not just clear it), that the board rests on its ledge,
  and that every screw meets its pilot hole.

- `enclosure_render.py` and `enclosure_guide.png`, rendered from the real STLs.

- **GPL v3 licensing.** The project is now free software under the GNU General
  Public License, version 3 or later:
  - `LICENSE` — the licence text, checked byte-for-byte against the FSF's own
    `gpl-3.0.txt`.
  - `THIRD_PARTY_NOTICES.md` — Cropper.js (MIT, Chen Fengyuan), the 5×7 font
    (BSD 2-Clause, Adafruit Industries) and the base template designer (Chanchal
    Sakarde), each with its full licence text, taken from its own repository.
  - A GPL notice and `SPDX-License-Identifier` at the top of every source file.
    `web_page.h` is `GPL-3.0-or-later AND MIT`; `oled_display.h` is
    `GPL-3.0-or-later AND BSD-2-Clause`.
  - The legal notice at the bottom of the web page, which GPL v3 section 5(d)
    requires of programs with an interactive user interface, and in a comment at
    the top of the page's HTML.

### Changed

- The sketch header's project name is now "ESP8266 String Art CNC", matching the
  README and this file.

### Before publishing

- Put your own name and repository address in place of the two placeholders
  in the source headers and the web page footer. One find-and-replace each.
- Confirm the licence of *StringArt-CircleBase-Design*. The copy this project
  was built from doesn't state one. If it isn't your own work, you need the
  author's agreement before publishing it under the GPL.

---

## [1.12.1] — 2026-09-21

Documentation and tooling follow-up to the OLED release. No firmware
behaviour has changed.

### Fixed

- **The README pointed the limit switch at the wrong pin.** "Find Home never
  completes" still said to check the switch on D7, and the wiring notes still
  said D0 and D4 were kept free because of their boot roles. Both went out of
  date in 1.12.0, when the switch moved to D0 and the OLED took D4 and D7. The
  README has been rewritten against the current firmware and checked
  mechanically: every button and setting it names exists in the web page, all
  16 `/action` commands are documented, and every default it quotes matches the
  code.

- **The hardware scripts looked for the STLs in different places.** `parts.py`
  wrote them to whatever folder you ran it from, while `fitcheck.py` and
  `assembly.py` read them from `stl/`, so the checks only worked by accident.
  All three now use `stl/` next to the scripts, and work from any folder.

### Changed

- **Font credited correctly.** The 1.12.0 notes described the OLED font as part
  of a driver written from scratch. The driver is, but the 5×7 glyph table is
  the standard "glcdfont" as distributed in Adafruit-GFX (BSD licence).
  `oled_display.h` and the README now say so. Only a comment changed in the
  file.

### Added

- README: the order to set up a new machine in, why each pin is where it is,
  a note that **SCK** on 4-pin OLED modules is the same as **SCL**, and a
  warning that 6- and 7-pin modules are SPI and won't work.

- `.gitignore` for Python caches and the rendered assembly image.

### Upgrade notes

- If your STL files are at the top of the repo, move them: `git mv *.stl stl/`.
- The `.ino` and `web_page.h` are unchanged. Nothing needs re-flashing.

---

## [1.12.0] — 2026-09-21

### Added

- **0.96" OLED dashboard** (SSD1306, 128×64, I2C). Shows the nail at the feeder
  in large digits, the next nail, progress as a count and a bar, and a live
  countdown of time left. The header shows the machine's state — RUN, WRAP,
  FEED, HOMING, PAUSED, DONE — and inverts to flag CHECK POS or HOME FAIL.

- **Boot screen with the address.** Shows "Joining WiFi" while it connects,
  then the IP and `stringart.local` for eight seconds — or the fallback network
  name and 192.168.4.1. With no sequence loaded the dashboard keeps showing the
  address. Finding the IP without a serial monitor was the hardest part of
  first-time setup; this removes it.

- **Upside-down toggle** in Advanced → Motor, for however the display ends up
  mounted, plus a readout of whether one was detected and at which address.

- `oledAddr` and `oledFlip` in `/status`; one more line in `/config.txt`.

### Changed

- **The limit switch has moved from D7 to D0**, and now needs a 10k pull-up
  resistor from D0 to 3V3. The OLED needs two I2C-capable pins: D1/D2 — the
  ESP8266's usual pair — are the stepper, D8 must be LOW at boot so an I2C
  pull-up stops the board booting, and D0 is an RTC pin the I2C driver can't
  use. That leaves D4 and D7 for the display. **The stepper and servo wiring
  are unchanged.**

- `HAS_LIMIT_SWITCH` now defaults to `false`. An unwired D0 floats, and homing
  against noise is worse than not homing. Set it `true` once the switch and
  resistor are in. Find Home is refused cleanly when it is off, instead of
  spinning a turn and a quarter and reporting failure.

### Fixed

- `hasLimitSwitch` in `/status` was always `true`: it tested an unsigned pin
  number with `>= 0`. Every switch read now goes through one
  `limitTriggered()` helper.

### Notes

- **No library needed.** The driver is written into `oled_display.h` — an
  init sequence, a 1 KB framebuffer, a 5×8 font and a flush — so the sketch
  still builds on the bare ESP8266 core. That file must sit in the sketch folder
  alongside the `.ino` and `web_page.h`.

- The display never holds up the stepper. It skips redraws while the disc is
  moving, sends one 128-byte page per loop pass (about 4 ms) instead of the
  whole frame at once, and sends nothing when the picture has not changed.

- Verified off-device: the drawing code compiles on a PC and renders the actual
  screens; the I2C transport was checked against a recording stub for correct
  command framing, a 1024-byte frame over exactly 8 passes, no transaction over
  17 bytes (safe on cores with a 32-byte Wire buffer), zero traffic when idle,
  and zero traffic with no display fitted.

- Power the display from **3V3, not 5V**. The module's pull-ups go to whatever
  powers it, and the ESP8266's pins are not 5 V tolerant.

---

## [1.11.0] — 2026-09-21

### Changed

- **The disc sweep is set by dragging, like the servo angles.** The two wrap
  numbers are now presented as **Ahead** — where the tube swings out, past the
  nail in the direction of travel — and **Behind** — where it swings back in on
  the other side. Both are sliders, and the disc moves to follow them as you
  drag, parked relative to the nail at the feeder, so you set them by watching
  where the tube crosses rather than by guessing step counts.

  Letting go saves. The disc stays where you left it so you can still see the
  position. Each slider shows its value in steps and in nails, and flags when it
  differs from the computed default. The range scales with the nail pitch, up to
  two nails either side.

  Ahead and Behind can now differ — the old offset/sweep pair could express this
  but made it hard to reason about. Storage is unchanged (`wrapSteps` = ahead,
  `wrapSweep` = ahead + behind), so existing settings carry over.

- A **Preview as if travelling −** toggle, because real wraps hand themselves
  off the direction of travel. The preview reproduces the real stop positions
  exactly in all four combinations of travel direction and the global flip.

### Added

- **Walk through one wrap by hand**: five buttons making the same five moves the
  sequencer makes — disc ahead, tube out, disc behind, tube in, back on the
  nail. The way to check the thread actually hooks with your settings before
  committing to a run.

- `wrappreview` action; `previewNail` and `discOffset` in `/status`, with a
  readout of where the disc sits relative to the nail.

---

## [1.10.0] — 2026-09-20

### Changed

- **Servo angles are set by dragging, not by typing.** Rest and Feed are now
  sliders, and the arm follows them live while you drag, so you set them by
  watching where the tube actually goes. Letting go saves and parks the arm back
  at rest. Requests are throttled to one per 120 ms — a range input fires on
  every pixel and the ESP8266 does not need sixty a second to nudge a servo.

  Added **Hold at rest**, **Hold at feed** and **Swing rest → feed → rest** so
  the real motion can be watched at the configured slew speed, plus a readout of
  where the arm is and how big the throw is.

- **Wrap geometry is stored as real numbers**, not `0 = work it out`. The values
  are filled in from the nail count at first boot, on Restore defaults, and
  whenever the nail count changes — step counts are meaningless against a
  different pitch. Each field shows what it works out to in nails, and flags
  when it differs from the computed value.

- **The sweep is now exactly twice the approach offset.** Rounding the two
  independently left the loop off centre: at 360 nails it crossed the ring at
  +0.53 and −0.44 of a pitch instead of mirroring. Now every nail count gives a
  symmetric loop — 360 nails is +0.527 / −0.527.

### Added

- **Reset to the values for this nail count** button, for getting back to the
  computed geometry after experimenting.

- `servotest` action; `servoAngle`, `autoLead` and `autoSweep` in `/status`.

---

## [1.9.1] — 2026-09-19

### Fixed

- **Half the chords never hooked the thread.** The wrap loop was signed by the
  fixed `wrapDir` constant, but the direction the disc travels to reach a nail
  changes from chord to chord. So on chords running one way the sweep reversed
  the approach — the little hooking move, which caught — and on chords running
  the other way the sweep simply continued the approach, the disc carried
  straight on through the nail, and the thread was dropped.

  The two cases produce mirror-image loops. Only one of them puts the tube on
  the far side of the nail from the thread trailing behind it, so only one
  wraps. This is why it worked clockwise and did nothing anticlockwise.

  The loop is now handed off the measured direction of travel: overshoot past
  the nail in the direction the disc is already going, sweep back across it,
  land on it. Both chord directions now make the same reversing move.

### Changed

- `wrapLeadSteps()` / `wrapSweepSteps()` split into magnitudes
  (`wrapLeadMag()`, `wrapSweepMag()`) and signed accessors, with the sign from
  `wrapApproachDir * wrapDir`. `startWrap()` measures the approach direction
  from the shortest-path delta before it starts moving.

- *Approach from the other side* still works, flipping both directions together
  rather than pinning them to one.

### Added

- **Test wrap from − / from +** buttons, which park the disc six nails to one
  side and then wrap, so each approach direction can be checked on its own.
  Both should now produce the same reversing move at the nail.

- The wrap breakdown reports the overshoot and sweep in nail pitches and which
  direction the last wrap was handed. `wrapApproachDir` added to `/status`.

---

## [1.9.0] — 2026-09-17

### Added

- **Greeting card PDF.** Under the Design section: your cropped photo and the
  generated string art on one A4 landscape sheet, folded down the middle, with
  an optional title and message. Downloads as a real PDF.

  Written from scratch rather than with a library. A PDF can carry a JPEG's
  bytes verbatim as a DCTDecode stream, so the whole writer is about sixty
  lines; jsPDF would do the same job for roughly 300 KB of PROGMEM, which the
  ESP8266 has not got to spare.

  The output was verified against a PDF parser: A4 landscape mediabox
  (842 × 595 pt = 297 × 210 mm) at an effective 150 dpi.

- Layout notes: a landscape sheet folded down the middle keeps both halves
  upright, so nothing needs rotating. The right half is the cover — string art
  with the title beneath and a nails/chords credit line. The left half is the
  inside — the source photo, circular-cropped to echo the nail ring, with the
  message wrapped below it. The fold line is optional.

### Notes

- The card canvas is 1754 × 1240 px, about 9 MB in the browser. Fine on a phone,
  but it is built only when you press the button, not kept around.

- Print at 100% scale with fit-to-page off, as with the base template.

---

## [1.8.0] — 2026-09-17

### Added

- **Run clock and ETA** under the progress bar in the Wrap section: elapsed
  time, remaining time, the clock time it will finish at, and the measured
  seconds per nail.

  The estimate is **measured, not predicted**. The configured feed cycle time
  ignores disc travel, which varies with how far apart consecutive nails are,
  and ignores however long you actually take between presses in manual mode.
  The firmware keeps an exponential moving average of real nail-to-nail times
  instead, and the UI says "measuring" rather than guessing until it has data.

- Samples outside 0.2–120 s are dropped, and the timestamp is cleared on Stop
  and on Go to step, so a pause is never folded into the average.

- The run clock only ticks while auto is running, so it measures machine time
  rather than wall time.

- `avgNailMs` and `elapsedMs` in `/status`, both persisted in `/state.txt`, so
  the estimate survives a reboot mid-piece instead of restarting from nothing.

---

## [1.7.0] — 2026-09-16

### Added

- **Calibrate the nail position**, in the Wrap section. Jog the disc a nail at
  a time until the right one lines up with the feeder, then say which one it
  is. The firmware solves for the offset that makes that true and applies it to
  every future move. Your place in the sequence is untouched — this corrects
  where the *disc* is, not where you are in the *chord list*.

- **Steps-per-turn calibration.** Spin a set number of whole turns, report how
  many nails past or short of the start it finished, and the firmware corrects
  its steps-per-revolution figure. This separates the two causes of drift:
  a constant creep every revolution is a wrong step count, random wandering is
  missed steps.

  It also settles the 64:1 vs 63.68395:1 question empirically. A disc that
  finishes 18 nails short over 10 turns measures 4075.6 steps — which is the
  tooth-count ratio, found by measurement rather than assumed.

- **Re-home every N nails** (needs the limit switch). The only thing that
  actually clears missed steps on a long run. Progress is kept, so it resumes
  on the same chord.

- `stepsPerRevX100`, `stepsPerRevDefX100`, `nailOffsetSteps`, `rehomeEvery`,
  `calRunning` and `hasLimitSwitch` in `/status`; new `jog`, `setnail`,
  `calmove` and `calreport` actions. Three more lines in `/config.txt`.

### Changed

- **Steps per revolution is now a runtime value**, not a compile-time constant,
  so calibration can write it back. `nailToStep()` splits into `nailBaseStep()`
  plus the calibration offset, which is what lets the re-sync solve for it.

- Auto-advance waits for `calRunning`, so a calibration spin cannot be
  interrupted by the sequence.

### Notes

- Re-sync corrects a *constant* error. If the disc keeps wandering off after
  you have corrected it, that is missed steps, and the fixes are mechanical:
  raise the step delay, reduce the disc's inertia, check nothing is binding.
  Re-homing periodically papers over it; it does not cure it.

---

## [1.6.1] — 2026-09-16

### Added

- **Servo speed control.** `Servo.write()` commands a position and the SG90
  slams to it as fast as its gearing allows — there is no speed parameter. The
  arm is now walked to its target in increments (`servoSlewDeg` degrees every
  `servoSlewMs` ms), non-blocking, so the disc and web server keep running
  while it creeps. A 90° swing takes 900 ms at the defaults instead of roughly
  150 ms. Both the wrap cycle and the plain pay-out pulse use it.

- **Two waits where the thread has to seat**, which are the ones that decide
  whether a wrap holds:
  - `wrapHoldInMs` (400 ms) after the tube reaches the feed position
  - `wrapHoldSweepMs` (400 ms) after the sweep, before the tube comes back

- **Sweep distance** as its own setting, independent of the approach offset.
  Previously one number controlled both, so the approach could not be moved
  without changing how far the thread was carried.

### Changed

- **Wrap cycle reordered** to approach → settle → tube in → wait → sweep →
  wait → tube out → recover → land. The sequencer waits on `servoBusy()` as
  well as `stepping`, so a phase never starts while the arm is still slewing.

- The wrap breakdown now reports where the tube crosses the ring at **both**
  ends in nail pitches, the servo travel time, and the total fixed cycle time.
  It warns when either crossing would land on a nail rather than in a gap.

- "Overshoot each way" is now "Approach offset" — 0 stops on the nail itself
  before the servo moves, which is what you want if the tube has room to cross
  there.

### Notes

- Default cycle is about 3.8 s per nail of fixed time, plus disc travel and
  your dwell. Most of that is the two 900 ms servo slews; raise `servoSlewDeg`
  or drop `servoSlewMs` once you know how slow it actually needs to be.

- Five more lines in `/config.txt`. Older files load unchanged.

---

## [1.6.0] — 2026-09-16

### Added

- **Wrap cycle.** The feeder now traces a closed loop around each nail instead
  of pushing out and back along one line. With a single servo axis the disc
  supplies half the loop, so the cycle is six phases:

  | Phase | What moves |
  |---|---|
  | Approach | disc, to half a nail short of the target |
  | Settle | nothing — let the disc stop ringing |
  | Out | servo swings the tube outside the ring |
  | Sweep | disc, one whole nail pitch, tube still out |
  | In | servo brings the tube back inside |
  | Land | disc backs up half a pitch onto the nail |

  Out, Sweep and In are the loop. Land does not undo it: the tube stays inside
  the ring and never re-crosses the thread.

- **Auto overshoot** of half a nail pitch, so the ring crossings fall exactly
  midway between nails — the tube passes through a gap rather than into a nail,
  and the loop encloses the target and nothing else. Overridable in steps.

- **Approach-from-the-other-side** toggle, which reverses the handedness of
  every wrap. Flip it if wraps shed.

- **Test one wrap** button, running a single cycle on the current nail for
  tuning without committing to a run. New `wraptest` action.

- A wrap breakdown in the UI showing the overshoot in steps, degrees and
  fractions of a nail pitch, warning when it is too small to clear the nail or
  large enough to enclose two.

- `wrapMode`, `wrapSteps`, `wrapAutoSteps`, `wrapDir` and `wrapBusy` in
  `/status`; the first three persisted as three more lines in `/config.txt`.

### Changed

- **The disc and the feeder may now move in the same cycle.** Auto-advance
  waits for `wrapBusy()` rather than keeping the two apart. The old mutual
  exclusion is correct for a feeder that only pays out thread and fatal for one
  that has to wrap — the Sweep phase *is* the disc moving with the servo
  extended.

- Advances go through one `presentNail()` entry point, which hands off to the
  wrap sequencer or falls back to the old move-then-pulse when wrapping is off.

- Stop, Set Home and Find Home abort a wrap in progress and return the servo to
  rest, so the tube is never left parked out over the nails.

- "Pulse duration" relabelled "Servo travel" — in wrap mode it is how long the
  servo is given to swing, not how long thread is paid out.

### Notes

- Wrapping is on by default. Turning it off restores the old pay-out pulse,
  which cannot hook a nail; the UI says so.

- A wrap costs one normal move plus two short ones (about 1.5 nail pitches of
  extra travel), because Approach goes straight to the pre-position rather than
  stopping on the nail first.

---

## [1.5.0] — 2026-09-16

### Fixed

- **Resume after a power cut came back one nail behind.** `saveState()` was
  called immediately after `beginMoveToStep()`, at which point `currentStep`
  still held the position the disc was leaving, not the one it was heading to.
  The move then completed without saving again, so the file permanently
  described the previous nail. State is now written twice per nail: once when a
  move starts, recording the target and that a move is in flight, and once when
  it lands, recording the position actually reached.

### Added

- **Interrupted-move detection.** If power was cut mid-move, the position is
  restored as the intended target but flagged unverified, and a banner in the
  Wrap section asks for a home before carrying on. Progress is kept either way.
  Any homing operation clears the flag.

- **Find home on power-up** (Advanced → Motor, off by default). With the limit
  switch fitted, the machine homes against it at boot and drives back to the
  saved nail, recovering an absolute reference without you touching anything.
  It deliberately does not start running again — thread may be loose, and
  starting an unattended machine on power-up is a bad default.

- **Go to step #** in the Wrap section: jumps to a position in the sequence and
  takes progress with it, so the wrap continues from there. New `gotostep`
  action on `/action`. It shows the valid range and where you currently are.

- **Go to nail #** promoted out of the collapsed panel into the Wrap section
  alongside it. This one moves the disc without changing progress — the two are
  now labelled so the difference is obvious. Both accept Enter.

- `positionKnown` and `autoHomeOnBoot` in the `/status` JSON; `autoHomeOnBoot`
  persisted as an eleventh line in `/config.txt`.

- A resume line on the serial console at boot, reporting the step, the disc
  position, and whether it is verified.

### Notes

- The state file gained two lines. Files written by earlier firmware still load
  — the missing fields fall back to "no move in flight", which is correct for
  anything that was sitting idle.

- Two small LittleFS writes per nail. The filesystem wear-levels these, but on
  a several-thousand-chord piece it is a reason not to run the dwell down to
  near zero.

---

## [1.4.1] — 2026-09-15

### Fixed

- **Sketch failed to compile**, reporting `expected constructor, destructor, or
  type conversion before '(' token` against a line of minified JavaScript
  inside the web page.

  The Arduino build does not hand your `.ino` to the compiler directly. It
  preprocesses it first — concatenating files, inserting `#include <Arduino.h>`,
  scanning for function definitions and injecting generated prototypes. That
  scan does not reliably understand C++11 raw string literals, and on a literal
  approaching 100 KB it can cut the string short. Everything past the cut is
  then parsed as C++, and the first thing it hits is the vendored Cropper.js
  bundle.

  The literal itself is valid: it compiles cleanly under g++ on its own. The
  corruption happens in Arduino's preprocessing step, which only ever runs on
  `.ino` files.

### Changed

- **The web page moved to `web_page.h`.** Arduino does not preprocess `.h`
  files, so the raw string is now out of reach of the step that was breaking
  it. The sketch is still one sketch: keep `web_page.h` next to the `.ino` in
  the same folder and it compiles and flashes in one click as before. Do not
  paste the page back into the `.ino`.

- **All function prototypes are now declared explicitly** near the top of the
  sketch. Arduino normally generates these by scanning the `.ino`; declaring
  them by hand costs nothing and means the build no longer depends on that scan
  succeeding.

- The `.ino` dropped from about 2160 lines to about 760, which makes the
  firmware logic considerably easier to navigate.

---

## [1.4.0] — 2026-09-15

### Fixed

- **Settings appeared not to take effect.** `/status` is polled once a second
  and its reply was written straight into every input, so a field being typed
  in got reset mid-keystroke. A longer settle time entered by hand was wiped
  before it could be saved. Fields now go "dirty" on the first keystroke and
  are left alone until saved or reset, and a focused field is never written to.

### Changed

- **Default settle raised from 250 ms to 800 ms, recover from 200 ms to
  400 ms.** A quarter-second settle is close enough to instant that the servo
  still appeared to fire the moment the nail arrived. The default feed cycle is
  now 1.50 s (0.80 settle + 0.30 pulse + 0.40 recover).

- **All persistent settings collected into one "Advanced settings" section**,
  grouped as Motor, Feed cycle and Feeder servo angles, with a single Save.
  They were previously split across two collapsible panels in different
  sections with separate save buttons. The Wrap section keeps only "Jump to a
  nail"; the Feed section keeps only the auto-feed toggle and Feed now.

- Boot defaults are now named constants (`DEF_FEEDER_SETTLE_MS` and friends) at
  the top of the sketch rather than literals scattered through the code.

### Added

- **Restore defaults** button, handled server-side via `reset=1` on `/config`
  so the page never carries its own copy of the default values.

- **Live feed-cycle breakdown** that updates as you type, before saving:
  settle → pulse → recover, the total feed time, the dwell, and the resulting
  seconds per nail. Warns when settle is under 0.3 s.

- The compiled-in defaults are published in the `/status` JSON under
  `defaults`.

- Unsaved changes are marked with an asterisk on the Save button, and saving
  or resetting reports success or failure inline.

---

## [1.3.0] — 2026-09-15

### Fixed

- **Nail count had to be set in three places** — the Design slider, the base
  template designer, and the machine settings field — and nothing kept them
  in agreement. They are now three views of one value (`window.NailCount`):
  editing any one updates the others immediately and saves to the machine
  after a short pause. A `/status` poll arriving mid-edit no longer yanks the
  field back, because values from the machine are ignored while a local edit
  is unsaved.

- **Feeds could be skipped entirely on a zero-length move.** The feed was
  triggered by the move-completion event, but `beginMoveToStep()` leaves
  `stepping` false when a move works out to zero steps — a sequence repeating
  a nail, or two nails rounding to the same step. The feed never fired and
  auto mode stalled waiting on a dwell that was never restarted.
  `armFeedAfterMove()` now handles that case directly.

### Changed

- **The feeder is a four-phase cycle instead of an immediate pulse:**
  settle → pulse → recover → idle. The servo now waits `feederSettleMs`
  (default 250 ms) after the nail arrives before grabbing the thread, so it
  isn't feeding into a disc that is still ringing, and waits
  `feederRecoverMs` (default 200 ms) after returning to rest before the disc
  is allowed to move again.

- **Auto-advance waits for the feeder,** not just the stepper. A move can no
  longer start while thread is being paid out.

- **The auto-advance interval now means dwell after the feed**, measured from
  the moment the feed cycle completes, rather than an interval that overlapped
  the move and the feed.

- Next / Prev / Goto are refused while a feed is in progress rather than
  dragging thread out of the servo's grip.

- The Design section's nail control is relabelled "Nails" and its range
  widened from 60–400 step 4 to 24–720 step 1, so it can reach every count the
  base designer can offer.

### Added

- `feederSettleMs` and `feederRecoverMs` settings, persisted to `/config.txt`
  (two more appended lines; older files still load) and editable under feeder
  settings, with a readout of the resulting per-nail cycle time.

- `feederSettleMs`, `feederRecoverMs` and `feederBusy` in the `/status` JSON;
  the progress line shows "feeding thread…" while a cycle runs.

### Removed

- The base designer's "Use this nail count" button — the count syncs on its
  own now. The field shows "saving…" or "on machine" instead.

---

## [1.2.0] — 2026-09-15

### Added

- **Base template designer**, merged into the machine's own page as section
  *4 · Base template*. Draws the numbered nail ring for the physical base,
  with live preview, real-size SVG export, optional laser-cut circle, centre
  drill mark and red nail dots. Adapted from StringArt-CircleBase-Design by
  Chanchal Sakarde.

- **Motor-synchronised nail layout.** The designer reads the live motor
  profile from `/status` instead of hardcoding a step count, so a template can
  never be printed for a configuration the firmware isn't running. It reports
  steps per nail, degrees per nail, nail pitch in mm, and — when the count
  doesn't divide the step grid evenly — the worst-case placement error in both
  degrees and millimetres at the chosen radius.

- **Suggested nail counts.** When the chosen count doesn't divide evenly, the
  designer offers the nearest counts that do, filtered to ones that still
  leave at least 3 mm between nails at the current radius.

- **Warnings for unbuildable rings**: fewer than 2 steps between neighbouring
  nails (the indexer cannot separate them), or a nail pitch under 3 mm.

- **"Use this nail count"** pushes the designer's count straight to the
  machine's `numNails` setting, so the template, the chord generator and the
  indexer cannot drift apart.

- `internalSteps`, `halfStep`, `gearRatioX100000` and `stepsPerRevX100` added
  to the `/status` JSON.

### Changed

- **Motor geometry is now a single derived profile.** `MOTOR_INTERNAL_STEPS`,
  `MOTOR_HALF_STEP` and `MOTOR_GEAR_RATIO_X100000` are the only inputs;
  `STEPS_PER_REV_X100` and `STEPS_PER_REV` are computed from them at compile
  time via `constexpr`. Nothing else in the firmware hardcodes a step count.

- **Default gear ratio changed from 63.68395:1 back to 64.00000:1**, giving
  2048 full-steps / 4096 half-steps per revolution as specified. This makes
  counts like 64, 128 and 256 land exactly on step boundaries. The measured
  tooth-count ratio is kept in the source as a one-line alternative, together
  with a ten-revolution test for deciding which one your motor actually is.
  See "Which gear ratio" in the README — at 4096 half-steps the worst-case
  *within-revolution* rounding error is only ±0.044°, so the choice matters
  for accumulated full-revolution error, not for individual nail placement.

### Notes

- The designer places nail 0 at three o'clock with numbering increasing
  clockwise, matching `pinPositions()` in the chord generator and the Python
  generator. Physical nail index, generated sequence and indexer position all
  refer to the same nail.

- The page grew by roughly 9 KB of PROGMEM. On a 4 MB ESP8266 there is ample
  room; on a 1 MB module check the build size after flashing.

---

## [1.1.0] — 2026-09-14

The indexer was presenting the wrong nail. Asking for nail 258 brought nail
102 to the feeder; 109 brought 251; 263 brought 97; 179 brought 181. Every
reading came out as `numNails − requested`, which is the signature of a
mirrored rotation rather than a step-count error.

### Fixed

- **Rotation direction (the bug).** The nails ride on the rotating disc and
  the feeder is fixed, so to present nail N the disc must turn *backwards* by
  N — nail N starts N steps ahead of the feeder and has to travel back to it.
  The old `nailToStep()` turned forwards, so nail `numNails − N` arrived
  instead. A new `dirSign` constant, defaulting to `-1`, applies the correct
  sense.

- **Steps per revolution.** `STEPS_PER_REV` was 4096, which assumes a 64:1
  gearbox. The 28BYJ-48's real gear ratio is 63.68395:1, giving
  64 × 63.68395 = **4075.77** half-steps per output revolution. The old value
  placed every nail roughly 0.5% too far round — about 1.8° of accumulated
  error by the time the disc returned to nail 0, enough to visibly smear the
  last chords of a long sequence. Nail-to-step conversion now uses the exact
  figure held as a scaled integer (`STEPS_PER_REV_X100 = 407577`), so there is
  no floating-point maths on the ESP8266 and no drift.

- **Position tracker overflow.** `currentStep` was never wrapped after a move
  completed (`targetStep = currentStep + delta` could run past one revolution
  or below zero), so it grew without bound across a long run and was written
  to `/state.txt` that way. It is now normalised to `0 … STEPS_PER_REV−1`
  whenever a move finishes, and on load, so rounding cannot accumulate across
  thousands of chords.

- **Stale saved state.** `loadState()` normalises the restored step position,
  so a `/state.txt` written by 1.0.0 (in 4096-step units, possibly unbounded)
  no longer puts the disc in a nonsensical place on first boot after upgrade.

### Added

- **Reverse-direction toggle** in the web UI under *Jump to nail # / machine
  settings*. Flips `dirSign` live and persists it to `/config.txt` — no
  reflash needed to correct a mirrored machine.

- **Direction self-test** button. Sends the disc to nail 0, ¼, ½, ¾ and back
  to 0, naming each stop on screen as it goes, so the nail actually arriving
  at the feeder can be checked against the nail requested.

- `dirSign` exposed in the `/status` JSON and accepted by `POST /config`.

### Changed

- `/config.txt` gained an eighth line holding `dirSign`. Files written by
  1.0.0 have seven lines; `readConfigLine()` already returns the caller's
  default for missing lines, so older config files load cleanly and pick up
  `dirSign = -1`.

### Upgrade notes

1. Flash the sketch. Existing `/sequence.csv`, `/config.txt` and `/state.txt`
   on LittleFS are preserved and remain readable.
2. Run **Find Home** (or **Set Home**) once — the step scale changed from 4096
   to 4076 units per revolution, so any previously saved position is no longer
   meaningful.
3. Run the **direction test**. If the nail arriving does not match the nail
   named, flip *Reverse rotation direction* and re-home.

### Not a firmware issue

If the wrapping indexes correctly but the finished artwork comes out
left-right flipped, the generator is numbering nails the opposite way round
the canvas from the physical frame. Fix it in the generator's nail layout —
flipping `dirSign` back would break indexing again to compensate for an
unrelated mirror.

---

## [1.0.0] — Initial release

### Added

- Web-controlled nail indexer for a 28BYJ-48 stepper driven through a ULN2003
  board, with Next / Prev / Auto advance and live progress.
- Browser-based string art generator on the same page: photo upload, crop via
  Cropper.js, chord solver, live preview, downloadable step list.
- Direct upload of a generated sequence to the machine over `POST /upload`,
  stored on LittleFS at `/sequence.csv`.
- Optional SG90 feeder servo with adjustable rest angle, feed angle and pulse
  length; fires on demand or automatically after each advance.
- Optional limit switch for physically verified homing, with a 1.25-revolution
  safety cap and an error flag when the switch never trips.
- Non-blocking stepper, servo and homing routines so the web server stays
  responsive throughout.
- Persistent sequence, machine config and progress across reboots.
- WiFi station mode with softAP fallback (`StringArtCNC`) and mDNS at
  `stringart.local`.

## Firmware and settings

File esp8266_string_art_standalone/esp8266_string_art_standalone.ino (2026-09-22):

// SPDX-License-Identifier: GPL-3.0-or-later
// Copyright (C) 2026 YOUR NAME
//
// This file is part of ESP8266 String Art CNC.
//
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
/*
  ESP8266 String Art CNC
  ======================
  Drives a 28BYJ-48 stepper (via a ULN2003 driver board) that rotates a
  disc of nails. The motor's job is purely to index: bring the next nail
  in the sequence to a fixed pointer on the frame so you can wrap the
  thread by hand, then advance to the next one.

  Control is via a small web page served over WiFi (works from a phone
  on the same network) showing the current/next nail and Next/Prev/Auto
  buttons. Upload the sequence.txt produced by string_art_generator.py
  from that same page.

  Two optional extras, both non-blocking like everything else here:
    - FEEDER_SERVO (SG90): a small servo that nudges/releases a bit of
      thread on each nail advance. It can fire automatically after every
      "next" step (toggle "Auto-feed" in Settings) or on demand via the
      "Feed now" button. Rest/feed angle and pulse length are adjustable.
    - LIMIT_SWITCH: a lever/microswitch mounted on the frame so the
      rotating disc trips it once per revolution at the physical nail-0
      mark. "Find Home" slowly rotates the disc until the switch trips,
      then declares that the true nail 0 -- a physically-verified
      alternative to "Set Home" (which just relabels wherever the disc
      currently sits, without checking anything).

  ----------------------------------------------------------------------
  CHANGES IN THIS REVISION
    1. Rotation direction. The nails ride on the disc and the feeder is
       fixed, so to present nail N the disc must turn BACKWARDS by N.
       The old code turned forwards, so nail (numNails - N) arrived
       instead -- 258 showed up as 102, 109 as 251, 263 as 97.
       Fixed by dirSign, which now defaults to -1 and is toggleable
       from the web UI without reflashing.
    2. Steps per revolution. 4096 was an approximation; the true figure
       is 4075.77 (gear ratio 63.68395:1, not 64:1). 4096 drifts about
       1.8 deg per revolution. The nail->step maths now uses the exact
       value in integer arithmetic.
    3. Position tracking. currentStep is normalized to one revolution
       when each move finishes, so rounding cannot accumulate over
       thousands of chords, and the saved state file stays small.
    4. A "Run direction test" button in machine settings: the disc
       visits nail 0, 1/4, 1/2, 3/4 and back, naming each one as it
       goes so you can check the nail at the feeder matches.

  ----------------------------------------------------------------------
  WIRING (see the project guide for the full diagram):
    ULN2003 IN1 -> ESP8266 D1 (GPIO5)
    ULN2003 IN2 -> ESP8266 D2 (GPIO4)
    ULN2003 IN3 -> ESP8266 D5 (GPIO14)
    ULN2003 IN4 -> ESP8266 D6 (GPIO12)
    ULN2003 GND -> ESP8266 GND (common ground, required)
    ULN2003 "+" -> external 5V supply (do NOT power the motor from the
                   ESP8266's own 5V/3V3 regulator; share ground only)

    SG90 signal -> ESP8266 D3 (GPIO0)
    SG90 V+     -> external 5V supply (an SG90 can spike well past what
                   the ESP8266's onboard regulator can supply alongside
                   WiFi -- share the same external supply and GND as the
                   ULN2003, not the ESP8266's own 5V/3V3 pins)
    SG90 GND    -> common ground (same net as everything else above)

    OLED 0.96" SSD1306, I2C (optional):
      VCC -> ESP8266 3V3        (3.3 V, NOT 5 V -- the module's pull-ups go
                                 to whatever powers it, and the ESP8266's
                                 pins are not 5 V tolerant)
      GND -> GND
      SDA -> D7 (GPIO13)
      SCL -> D4 (GPIO2)
    Detected automatically at 0x3C or 0x3D. With nothing connected the
    firmware notices at boot and carries on without it.

    LIMIT_SWITCH (optional) -> MOVED from D7 to D0 (GPIO16):
      one leg to D0, the other leg to GND, and a 10k resistor from D0 to
      3V3. D0 has no internal pull-up, so the resistor is required.
      Then set HAS_LIMIT_SWITCH = true below.

    Why the pins are where they are: D1/D2 are the ESP8266's usual I2C
    pair but already drive the stepper. D8 must be LOW at boot, so an I2C
    pull-up on it stops the board booting. D0 is an RTC pin the I2C driver
    can't use. That leaves D4 and D7 for the display, and pushes the switch
    to D0. The stepper and servo wiring are unchanged.

    D3 (servo) and D4 (OLED SCL) must both read HIGH at reset. The servo
    input and the OLED's pull-up both leave them HIGH, so it boots
    normally. D4 is also the onboard blue LED on most boards -- it will
    flicker faintly while the display updates. That is harmless.

  Before flashing:
    1. Set WIFI_SSID / WIFI_PASSWORD below.
    2. Board Manager: install "esp8266" by ESP8266 Community.
    3. Tools > Board: e.g. "NodeMCU 1.0 (ESP-12E Module)".
    4. Tools > Flash Size: pick one with an SPIFFS/LittleFS partition.
    5. Library Manager: no extra libraries needed beyond the ESP8266 core
       (ESP8266WiFi, ESP8266WebServer, LittleFS, Wire are all bundled).
       The OLED driver is written into oled_display.h, not a library.
  6. Keep all three files together in the sketch folder:
       esp8266_string_art_standalone.ino, web_page.h, oled_display.h
  ----------------------------------------------------------------------
*/

#include <ESP8266WiFi.h>
#include <ESP8266WebServer.h>
#include <ESP8266mDNS.h>
#include <LittleFS.h>
#include <Servo.h>
#include <Wire.h>
#include <vector>
#include "oled_display.h"   // 0.96" SSD1306 dashboard -- see that file

// ---------------------------------------------------------------------------
// Explicit prototypes.
//
// Arduino normally generates these for you by scanning the .ino. Declaring
// them by hand costs nothing and means the build no longer depends on that
// scan succeeding -- which is the other half of the fix that moved the web
// page into web_page.h.
// ---------------------------------------------------------------------------
bool feederBusy();
String autoBlock();
bool limitTriggered();
void dashTick();
void dashBoot(const char *l1, const char *l2, const char *l3);
bool wrapBusy();
long stepsPerRev();
long homeStepCap();
bool servoBusy();
void servoGoTo(uint8_t a);
void servoSnapTo(uint8_t a);
void serviceServo();
long autoLeadMag();
long autoSweepMag();
void applyAutoWrapGeometry();
long wrapLeadMag();
long wrapSweepMag();
long wrapSignedLead();
long wrapSignedSweep();
long wrapSweepSteps();
void saveState();
void noteNailDone();
long wrapLeadSteps();
void startWrap(uint16_t nail, int8_t forceDir = 0);
void learnReset();
void learnFit();
void learnApplySpr(long newX100, uint16_t atFeeder);
void startVerify(uint16_t nail, bool doFeed);
void finishVerify();
void verifyAnswer(long v);
void serviceWrap();
void abortWrap();
void presentNail(uint16_t nail, bool doFeed);
uint16_t previewNail();
long discOffsetFromNail();
void writeCoils(uint8_t idx);
void coilsOff();
long normalizeStep(long s);
void beginMoveToStep(long target);
long nailBaseStep(uint16_t nail);
long nailToStep(uint16_t nail);
void requestFeed(bool settleFirst);
void armFeedAfterMove(bool wantFeed);
void serviceFeeder();
void startHoming(int8_t dir);
void saveState();
void noteNailDone();
void loadState();
void saveConfig();
long readConfigLine(File &f, long def);
void loadConfig();
void loadSequenceFromFile();
void parseAndSaveSequence(const String &body);
void sendCorsHeaders();
void handleCorsPreflight();
void handleRoot();
void handleStatus();
void handleUpload();
void handleConfig();
void handleAction();
void setupWiFi();

// ---------------- User configuration ----------------
const char *WIFI_SSID = "YOUR_WIFI_SSID";
const char *WIFI_PASSWORD = "YOUR_WIFI_PASSWORD";
const char *AP_FALLBACK_SSID = "StringArtCNC";
const char *AP_FALLBACK_PASSWORD = ""; // used only if STA connect fails
const char *HOSTNAME = "stringart";

// Stepper / driver pins
const uint8_t PIN_IN1 = 5;  // D1
const uint8_t PIN_IN2 = 4;  // D2
const uint8_t PIN_IN3 = 14; // D5
const uint8_t PIN_IN4 = 12; // D6

// Feeder servo (SG90) and home limit switch -- see the wiring notes above
// for why these two specific pins were picked among the remaining ones.
const uint8_t PIN_FEEDER_SERVO = 0;  // D3

// The OLED needs two I2C-capable pins. D1/D2 -- the usual I2C pair -- are the
// stepper. Of the rest, D8 must be LOW at boot (an I2C pull-up stops it
// booting) and D0 is an RTC pin the I2C driver can't use. That leaves D4, plus
// D7 -- which is why the limit switch has moved from D7 to D0.
const uint8_t PIN_OLED_SDA = 13;     // D7
const uint8_t PIN_OLED_SCL = 2;      // D4 -- held HIGH at boot by the module's pull-up

// Limit switch, now on D0. D0 has no internal pull-up, so fit a 10k resistor
// from D0 to 3.3V; the switch shorts D0 to GND when triggered, as before.
// Off by default: an unwired D0 floats, and homing against noise is worse than
// not homing at all. Set true once the switch and resistor are in.
const uint8_t PIN_LIMIT_SWITCH = 16; // D0
const bool HAS_LIMIT_SWITCH = false;

bool limitTriggered() {
  return HAS_LIMIT_SWITCH && digitalRead(PIN_LIMIT_SWITCH) == LOW;
}

// ---------------- Motor profile ----------------
//
// Everything downstream -- the nail->step maths, the status JSON, and the
// base-template designer in the web page -- derives from these three numbers.
// Change them here only; nothing else hardcodes a step count.
//
//   28BYJ-48, full-step mode : 32 x 64      = 2048 steps/rev
//   28BYJ-48, half-step mode : 32 x 2 x 64  = 4096 steps/rev
//
constexpr long MOTOR_INTERNAL_STEPS = 32;   // full steps per internal motor rev
constexpr bool MOTOR_HALF_STEP = true;      // this firmware drives half-steps
constexpr long MOTOR_STEP_MULT = MOTOR_HALF_STEP ? 2 : 1;

// Gear reduction, scaled by 100000 so it stays integer maths.
//
//   6400000 = 64.00000:1  -> 2048 full / 4096 half steps per rev
//             This is the figure printed on the motor and the one the base
//             designer is set up around. Nail counts that divide evenly into
//             4096 (64, 128, 256...) then land exactly on a step boundary.
//
//   6368395 = 63.68395:1  -> 2037.89 full / 4075.77 half steps per rev
//             The ratio you get by multiplying the actual gear teeth
//             (32/9 x 22/11 x 26/9 x 31/10). Many 28BYJ-48 units measure
//             this rather than a clean 64:1, in which case commanding a
//             full revolution with 4096 under-rotates by about 1.8 deg.
//
// To find out which one your motor is: home the disc, mark the frame, then
// send it to nail 0 ten times via "goto" with numNails set to 1 (ten full
// revolutions). If the mark comes back true, keep 6400000. If it has crept
// round by roughly 18 deg, switch to 6368395 and re-home.
constexpr long MOTOR_GEAR_RATIO_X100000 = 6400000L;

// Derived: steps per output-shaft revolution, x100 to keep the fractional
// part without floating point. 32 * 2 * 6400000 / 1000 = 409600 (=4096.00).
constexpr long STEPS_PER_REV_X100_DEF =
    MOTOR_INTERNAL_STEPS * MOTOR_STEP_MULT * MOTOR_GEAR_RATIO_X100000 / 1000L;

// Runtime, not constexpr, because the calibration routine measures the real
// figure and writes it back. The compiled value is only the starting point:
// whether your gearbox is 64:1 or the tooth-count 63.68395:1 is something the
// machine can work out for itself over ten revolutions.
long stepsPerRevX100 = STEPS_PER_REV_X100_DEF;
long stepsPerRev() { return (stepsPerRevX100 + 50L) / 100L; }

// Fixed offset between nail numbering and disc position, in half-steps.
// Re-synced from the UI when the nail at the feeder is not the one the
// firmware thinks it is -- which is what missed steps eventually cause.
long nailOffsetSteps = 0;

// Which way the disc turns to present a nail to the fixed feeder.
//
// The nails ride on the disc and the feeder does not move, so to bring nail N
// to the feeder the disc must rotate BACKWARDS by N -- nail N starts N steps
// ahead of the feeder and has to travel back. Turning forwards instead
// presents nail (numNails - N): ask for 258 and 102 shows up.
//
//   -1 = disc turns opposite to the nail numbering  (the correct default)
//   +1 = disc turns with the nail numbering
//
// Toggle it live from the web UI ("Reverse rotation direction") -- no reflash
// needed. Re-home after changing it.
int8_t dirSign = -1;

// ---------------- Adjustable defaults ----------------
// These are what the machine boots with before /config.txt is read, and what
// "Restore defaults" in Advanced settings writes back. Change them here if a
// different starting point suits your build better.
constexpr uint16_t DEF_NUM_NAILS       = 200;
constexpr uint16_t DEF_STEP_DELAY_MS   = 2;
constexpr uint32_t DEF_AUTO_MS         = 4000;
constexpr uint8_t  DEF_FEEDER_REST     = 0;
constexpr uint8_t  DEF_FEEDER_FEED     = 90;
constexpr uint16_t DEF_FEEDER_PULSE_MS = 300;
// The disc is still ringing the instant a move ends, and the thread needs a
// moment to stop swinging before the feeder grabs it. Feeding into that
// snatches the thread and gives uneven lengths. 800 ms is a deliberately
// generous starting point -- it is easy to wind down once you can see the
// motion, and much less obvious when it is too short.
constexpr uint16_t DEF_FEEDER_SETTLE_MS  = 800;  // after the nail arrives, before feeding
constexpr uint16_t DEF_FEEDER_RECOVER_MS = 400;  // after the servo rests, before moving on

uint16_t stepDelayMs = DEF_STEP_DELAY_MS; // between half-steps; lower = faster but can stall
uint16_t numNails = DEF_NUM_NAILS;    // must match --nails used in the generator
uint32_t autoAdvanceMs = DEF_AUTO_MS; // used only in "auto" run mode

// Feeder servo settings (persisted -- see save/loadConfig)
uint8_t feederRestAngle = DEF_FEEDER_REST;
uint8_t feederFeedAngle = DEF_FEEDER_FEED;
uint16_t feederPulseMs = DEF_FEEDER_PULSE_MS;
uint16_t feederSettleMs = DEF_FEEDER_SETTLE_MS;
uint16_t feederRecoverMs = DEF_FEEDER_RECOVER_MS;
bool feederAutoFeed = false;    // fire a pulse automatically after every "next" advance

// ---------------- Persistent files ----------------
const char *SEQ_FILE = "/sequence.csv";
const char *STATE_FILE = "/state.txt";
const char *CONFIG_FILE = "/config.txt";

// ---------------- Runtime state ----------------
ESP8266WebServer server(80);
std::vector<uint16_t> sequence;
int currentIndex = 0;        // index into `sequence` of the nail we're currently AT
long currentStep = 0;        // absolute half-step position of the disc
long targetStep = 0;
bool stepping = false;
int8_t stepDir = 1;
uint8_t halfStepIdx = 0;
unsigned long lastStepAt = 0;
bool autoRunning = false;
unsigned long lastAutoAdvanceAt = 0;

// Feeder servo (non-blocking: fire-and-return via millis(), like the stepper)
Servo feederServo;
// Feeder servo. A full feed is four phases, all non-blocking:
//
//   SETTLE  nail has arrived; let the disc and thread stop moving
//   PULSE   servo at feed angle, paying out thread
//   RECOVER servo back at rest; let the thread settle before the disc moves
//   IDLE    done -- the indexer is free to advance
//
// Auto-advance waits for IDLE, so a move never starts on top of a feed.
enum FeederPhase { FEED_IDLE, FEED_SETTLE, FEED_PULSE, FEED_RECOVER };
FeederPhase feederPhase = FEED_IDLE;
unsigned long feederNextAt = 0;
bool feederPendingAfterMove = false; // fire once the in-flight stepper move completes

// ---------------- Servo slew ----------------
//
// Servo.write() commands a position and the SG90 slams to it as fast as its
// gearing allows. There is no speed parameter. To move it slowly the angle has
// to be walked in small increments, which is what this does -- non-blocking,
// so the disc and the web server keep running while the arm creeps.
//
// Travel time = (angle to cover / servoSlewDeg) * servoSlewMs.
// At the defaults, a 90 degree swing takes 45 * 20 = 900 ms.
uint8_t servoCurrent = 0;
uint8_t servoTarget = 0;
unsigned long servoNextAt = 0;
uint8_t servoSlewDeg = 2;    // degrees per increment; larger = faster, coarser
uint16_t servoSlewMs = 20;   // ms between increments; larger = slower

bool servoBusy() { return servoCurrent != servoTarget; }

void servoGoTo(uint8_t a) { servoTarget = a; servoNextAt = millis(); }

// Jump without slewing -- used at boot and when the rest angle is edited.
void servoSnapTo(uint8_t a) {
  servoTarget = a;
  servoCurrent = a;
  feederServo.write(a);
}

void serviceServo() {
  if (servoCurrent == servoTarget) return;
  if ((long)(millis() - servoNextAt) < 0) return;
  int diff = (int)servoTarget - (int)servoCurrent;
  int stepDeg = servoSlewDeg < 1 ? 1 : servoSlewDeg;
  if (diff >= -stepDeg && diff <= stepDeg) servoCurrent = servoTarget;
  else servoCurrent = (uint8_t)((int)servoCurrent + (diff > 0 ? stepDeg : -stepDeg));
  feederServo.write(servoCurrent);
  servoNextAt = millis() + servoSlewMs;
}
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
void loop() {
  server.handleClient();
  MDNS.update();

  if (homing) {
    // Slow open-loop seek: step one half-step at a time until the limit
    // switch trips, or we give up after homeStepCap() half-steps (broken
    // wiring, a switch that never closes, etc.) rather than spin forever.
    if (millis() - lastStepAt >= stepDelayMs) {
      lastStepAt = millis();
      if (limitTriggered()) {
        currentStep = 0;
        targetStep = 0;
        stepping = false;
        positionKnown = true;   // the switch is an absolute reference
        verifyPending = false;
        learnReset();
        homing = false;
        if (resumeAfterHome) {
          // Boot-time recovery: the switch has given us a known zero, so drive
          // back to the nail the sequence was interrupted on. Progress is kept.
          resumeAfterHome = false;
          if (!sequence.empty() && currentIndex < (int)sequence.size()) {
            beginMoveToStep(nailToStep(sequence[currentIndex]));
            armFeedAfterMove(false);
          }
        } else {
          currentIndex = 0;   // a hand-requested home also restarts the piece
        }
        saveState();
        if (!stepping) coilsOff();
      } else if (homeStepCount >= homeStepCap()) {
        homing = false;
        homeError = true;
        currentStep = homeStartStep; // don't leave the position tracker corrupted
        coilsOff();
      } else {
        currentStep += homeDir;
        halfStepIdx = (uint8_t)(((halfStepIdx + (homeDir > 0 ? 1 : -1)) + 8) % 8);
        writeCoils(halfStepIdx);
        homeStepCount++;
      }
    }
  } else {
    // Non-blocking half-step advance toward targetStep
    if (stepping && millis() - lastStepAt >= stepDelayMs) {
      lastStepAt = millis();
      currentStep += stepDir;
      netSteps += stepDir;
      halfStepIdx = (uint8_t)(((halfStepIdx + (stepDir > 0 ? 1 : -1)) + 8) % 8);
      writeCoils(halfStepIdx);
      if (currentStep == targetStep) {
        stepping = false;
        // Snap the tracker back into 0..stepsPerRev()-1. Every move is planned
        // from an absolute target, so rounding error cannot accumulate across
        // thousands of chords.
        currentStep = normalizeStep(currentStep);
        targetStep = currentStep;
        coilsOff(); // de-energize coils while idle: less heat, no buzzing, no wasted current
        saveState(); // second write: the disc is here, and no move is pending
        if (feederPendingAfterMove) {
          feederPendingAfterMove = false;
          requestFeed(true);   // settle before feeding: the nail just arrived
        } else {
          lastAutoAdvanceAt = millis();
        }
      }
    }

    // Optional hands-free auto-advance. Waits for the feeder as well as the
    // stepper, so the disc never starts turning with thread still being fed.
    if (autoRunning && !stepping && !feederBusy() && !wrapBusy() && !calRunning &&
        !verifyPending &&
        !sequence.empty() &&
        currentIndex + 1 < (int)sequence.size() &&
        millis() - lastAutoAdvanceAt >= autoAdvanceMs) {
      noteNailDone();
      currentIndex++;
      // Periodic re-home wipes accumulated missed steps. Progress is kept, so
      // it picks straight back up on the same chord.
      if (rehomeEvery > 0 && HAS_LIMIT_SWITCH && ++sinceRehome >= rehomeEvery) {
        sinceRehome = 0;
        resumeAfterHome = true;
        startHoming(1);
      } else {
        presentNail(sequence[currentIndex], feederAutoFeed);
      }
      saveState();
      if (currentIndex + 1 >= (int)sequence.size()) autoRunning = false;
    }
  }

  // Feeder servo: advances the settle -> pulse -> recover cycle
  serviceFeeder();
  // Run clock: only ticks while auto is running, so pauses do not inflate it.
  {
    unsigned long now = millis();
    if (autoRunning && elapsedTickAt != 0) runElapsedMs += (uint32_t)(now - elapsedTickAt);
    elapsedTickAt = now;
  }

  // Calibration turns: a long run of whole revolutions, a revolution at a time
  // so each move stays inside one wrap of the step counter.
  if (calRunning && !stepping && calRemaining > 0) {
    long chunk = calRemaining > stepsPerRev() / 2 ? stepsPerRev() / 2 : calRemaining;
    calRemaining -= chunk;
    beginMoveToStep(normalizeStep(currentStep + chunk * dirSign));
  }  // Spin finished. Drop the flag now: it only exists to keep auto-run and the
  // servo out of the way WHILE the disc turns. Leaving it set until you press
  // Correct locked auto-run solid, invisibly, for anyone who spun the disc to
  // look and moved on. calRevs keeps the report open for as long as you like.
  if (calRunning && !stepping && calRemaining == 0) calRunning = false;


  // Wrap sequencer: interleaves disc moves and servo swings
  serviceWrap();
  // Servo slew: walks the arm toward its target one increment at a time
  serviceServo();
  // OLED: redraw if anything changed, one page per pass, never mid-move
  dashTick();
}

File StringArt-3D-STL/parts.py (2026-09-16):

#!/usr/bin/env python3
"""
String Art CNC -- printed parts generator.

Produces STLs for:
    motor_stand.stl    28BYJ-48 upright stand, shaft up
    disc_hub.stl       D-shaft hub the nail disc bolts to
    servo_post.stl     base + column for the SG90, height-adjustable
    servo_bracket.stl  slides on the column, holds the SG90 shaft-down
    servo_arm.stl      arm carrying the thread tube

EVERY DIMENSION IS A CONSTANT BELOW. Measure your own parts and edit -- the
28BYJ-48 and SG90 are cloned by dozens of factories and vary by a few tenths.
Run:  python3 parts.py
"""

import numpy as np
import trimesh
from shapely.geometry import Polygon, Point, box as sbox
from shapely.ops import unary_union

# ============================================================== parameters ===

# ---- 28BYJ-48 stepper (measure yours) ----
MOTOR_BODY_D      = 28.5   # body diameter + a little clearance
MOTOR_BODY_H      = 19.0   # body height, bracket face to bottom
MOTOR_EAR_SPACING = 35.0   # centre-to-centre of the two bracket holes
MOTOR_SHAFT_D     = 5.05   # shaft diameter (nominal 5.0)
MOTOR_SHAFT_FLATS = 3.10   # across the two flats (nominal 3.0)
MOTOR_SHAFT_USE   = 9.0    # usable shaft length above the boss

# ---- SG90 servo (measure yours) ----
SG90_BODY_L   = 23.2   # body length  (nominal 22.8 + clearance)
SG90_BODY_W   = 12.6   # body width   (nominal 12.2 + clearance)
SG90_TAB_HOLE = 27.8   # centre-to-centre of the mounting tabs
SG90_TAB_D    = 2.3    # tab screw clearance
SG90_SPLINE_D = 4.9    # output spline; press fit, PLA takes the teeth

# ---- fasteners ----
M3_CLEAR   = 3.4       # through-hole for an M3 screw
M3_TAP     = 2.5       # self-tapping pilot for M3 into plastic
M2_TAP     = 1.7

# ---- thread tube ----
TUBE_D     = 2.1       # outside diameter of your brass/steel guide tube

# ---- your machine (THESE ARE GUESSES -- measure and change) ----
NAIL_RING_R   = 200.0  # radius of the nail circle, mm
NAIL_HEIGHT   = 12.0   # how far the nails stand above the disc face
DISC_THICK    = 6.0    # thickness of the nail disc

SEG = 96               # cylinder facets

# ================================================================= helpers ===

def box(x, y, z, at=(0, 0, 0)):
    m = trimesh.creation.box(extents=(x, y, z))
    m.apply_translation(at)
    return m

def cyl(r, h, at=(0, 0, 0), axis="z"):
    m = trimesh.creation.cylinder(radius=r, height=h, sections=SEG)
    if axis == "x":
        m.apply_transform(trimesh.transformations.rotation_matrix(np.pi / 2, [0, 1, 0]))
    elif axis == "y":
        m.apply_transform(trimesh.transformations.rotation_matrix(np.pi / 2, [1, 0, 0]))
    m.apply_translation(at)
    return m

def slot2d(length, width, centre=(0, 0), vertical=False):
    """Rounded-end slot as a 2D polygon, for extruding."""
    r = width / 2.0
    L = max(0.0, length - width)
    cx, cy = centre
    if vertical:
        body = sbox(cx - r, cy - L / 2, cx + r, cy + L / 2)
        caps = [Point(cx, cy - L / 2).buffer(r, 64), Point(cx, cy + L / 2).buffer(r, 64)]
    else:
        body = sbox(cx - L / 2, cy - r, cx + L / 2, cy + r)
        caps = [Point(cx - L / 2, cy).buffer(r, 64), Point(cx + L / 2, cy).buffer(r, 64)]
    return unary_union([body] + caps)

def vslot_x(width, length, centre, depth):
    """Vertical slot: long axis up Z, bored through a wall along X.

    The obvious way to build this -- a 2D slot extruded and then rotated -- is
    easy to get wrong by one axis, which is exactly how the first version of the
    column ended up with a blind groove instead of a through-slot. Built from
    primitives on the axis it actually has to run along, there is nothing to
    mix up.
    """
    r = width / 2.0
    run = max(0.0, length - width)
    body = box(depth, width, run, centre)
    for sz in (-1, 1):
        body = body.union(cyl(r, depth,
                              (centre[0], centre[1], centre[2] + sz * run / 2),
                              axis="x"))
    return body

# Where the bracket bolts to the column. One place, used by both parts, so they
# cannot drift apart.
BOLT_Y      = 9.0    # two bolt lines either side of centre, resists twisting
BOLT_PITCH  = 18.0   # vertical spacing of the bracket's two bolt rows
# Slot ends, measured up the column from the board. The bottom has to clear the
# gusset, which fills the inside corner up to about z=32 -- a slot that starts
# lower looks open from the front but a bolt runs straight into the ramp.
SLOT_BOTTOM = 36.0
SLOT_TOP    = 94.0

def extrude(poly, height, at=(0, 0, 0)):
    m = trimesh.creation.extrude_polygon(poly, height)
    m.apply_translation(at)
    return m

def check(mesh, name):
    if not mesh.is_watertight:
        mesh.fill_holes()
    mesh.remove_unreferenced_vertices()
    e = mesh.bounds[1] - mesh.bounds[0]
    print(f"  {name:18s} {e[0]:6.1f} x {e[1]:6.1f} x {e[2]:6.1f} mm"
          f"   {mesh.volume/1000:6.1f} cm3   watertight={mesh.is_watertight}")
    return mesh

# ============================================================ 1 motor stand ==
# Two posts the motor's bracket bolts down onto, on a plate that screws to the
# board. The body hangs between the posts. Print as modelled: plate on the bed,
# posts upward. No overhangs, no support.
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

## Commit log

2026-09-14 String Art CNC Machine USING 28BYJ48 stepper Motor EPS8266 and SG90 Servo Motor as thread feeder
2026-09-16 Resume after a power cut came back one nail behind
2026-09-16 adding String Art 3D print STL file for setup
    [disc_hub.stl, motor_stand.stl, servo_arm.stl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]
2026-09-17 Display Estimation and added calibration for long run
2026-09-20 Half the chords never hooked the thread and **Test wrap from − / from +
2026-09-20 Wrap thread around and Feeder Angle runtime set
2026-09-21 added GUI config for Disk Slider for nail and thread setup on runtime
2026-09-21 Added 0.9 inch OLED as dashboard
    [disc_hub.stl, enclosure_box.stl, enclosure_lid.stl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]
2026-09-22 **Checkpoint test run that learns** - optionally stops every N nails to askwhether the right nail is at the feeder, fixes the run from your answer
    [esp8266_string_art_standalone.ino, web_page.h]
2026-09-22 updated circuit wiring svg image
    [case_v11.stl, disc_hub.stl, enclosure_box.stl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]

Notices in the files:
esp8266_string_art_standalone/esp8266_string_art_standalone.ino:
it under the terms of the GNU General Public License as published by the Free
